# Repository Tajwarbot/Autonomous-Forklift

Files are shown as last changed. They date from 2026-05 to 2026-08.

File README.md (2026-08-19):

# Vision-Guided Autonomous Forklift

A student-built autonomous material-handling robot that follows a guided line, picks up a box, reads a QR route command with a Raspberry Pi, selects the correct branch at a T-junction, delivers the[...]

> **Project status:** working educational prototype for a controlled track. It is not an industrial forklift, safety-rated AMR, or certified material-handling system.

---

## What the robot does

The robot uses two controllers with separate responsibilities:

- **Raspberry Pi 4B:** USB-camera image acquisition, QR detection/decoding, route-command generation.
- **Arduino Mega 2560:** IR line following, motor control, T-junction handling, fork-servo control, station detection, calibration, and mission state.

A QR code contains only one route character:

| QR content | Action at outbound T-junction |
|---|---|
| `l` | Turn left |
| `r` | Turn right |

On the return trip, the Arduino automatically uses the opposite turn so the robot can return to the pickup branch.

---

## System overview

```mermaid
flowchart LR
    CAM[USB Camera] --> PI[Raspberry Pi 4B\nOpenCV + pyzbar]
    PI -- "UART: l / r @ 9600 baud" --> MEGA[Arduino Mega 2560]

    IR[6-channel IR sensor array] --> MEGA
    MEGA --> LEFT[BTS7960\nLeft drive]
    MEGA --> RIGHT[BTS7960\nRight drive]
    LEFT --> LM[2 × left DC motors]
    RIGHT --> RM[2 × right DC motors]
    MEGA --> SERVO[Forklift servo]

    BAT[3S LiPo battery] --> POWER[Power distribution\n+ buck converters]
    POWER --> PI
    POWER --> MEGA
    POWER --> LEFT
    POWER --> RIGHT
    POWER --> SERVO
```

The Raspberry Pi does not directly drive the motors. It sends the decoded route to the Arduino, while the Arduino handles real-time movement and station/junction behavior.

---

## Mission flow

The following flow matches the current QR-based firmware logic.

```mermaid
flowchart TD
    A[Power on] --> B[Arduino loads saved IR calibration from EEPROM]
    B --> C[Start Raspberry Pi QR scanner]
    C --> D[Start Arduino line-following mode]
    D --> E[Follow line to pickup station]
    E --> F[Pickup station detected]
    F --> G[Lift box]
    G --> H[5 s settle / QR scan window]
    H --> I[Fixed pickup-station U-turn]
    I --> J[Follow line toward T-junction]

    J --> K{Valid QR route received?}
    K -- No --> L[Stop at junction and wait]
    L --> K
    K -- l --> M[Turn left]
    K -- r --> N[Turn right]

    M --> O[Follow line to target station]
    N --> O
    O --> P[Drop box]
    P --> Q[Set return state + reverse briefly]
    Q --> R[5 s settle pause]
    R --> S[Fixed drop-station U-turn]
    S --> T[Follow line back to T-junction]
    T --> U[Turn opposite to saved outbound route]
    U --> V[Return to pickup station]
    V --> W[Clear old route and start next cycle]
    W --> G
```

The firmware runs continuously until the robot is stopped or powered off; there is no automatic mission `End` state in the current Arduino loop.

---

## Suggested track layout

```text
LEFT DROP STATION                       RIGHT DROP STATION
        │                                        │
        │                                        │
        └────────────────┬───────────────────────┘
                         │
                         │
                    T-JUNCTION
                         │
                         │
                         │
                         │
                  PICKUP / HOME
```

For the current sensor logic, the track geometry matters:

- Normal guided line: usually one or two sensors active.
- Full T-junction region: all six sensors can become active.
- Pickup/drop station: all six sensors read the station background long enough to trigger the station routine.

The current firmware treats an all-clear sensor condition as a station after approximately 350 ms, so a completely lost line can also resemble a station. Keep the station geometry consistent and [...]

---

## Electrical architecture

circuit diagram

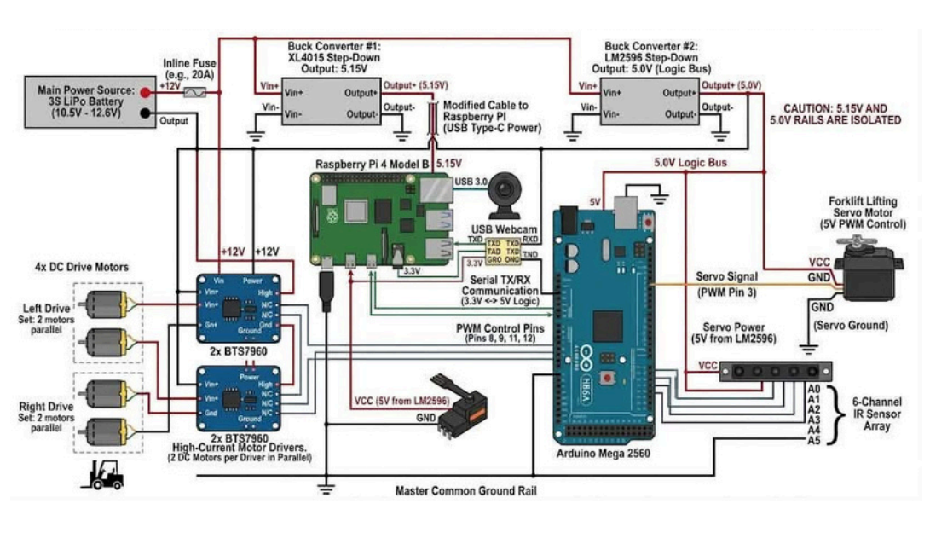
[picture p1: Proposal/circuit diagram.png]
Autonomous Forklift Circuit Diagram


### Detailed circuit diagram

```md
![Autonomous Forklift Circuit Diagram](Proposal/circuit diagram.png)
```

**Important:** the circuit diagram must match the firmware. In the current Arduino code, the fork servo signal is **D5**, while **D3** is the push button. Do not publish a schematic that labels the se[...] 

### Power notes

The current design uses separate regulated positive rails for the Raspberry Pi and 5 V logic/servo supply. Do not tie the **5.15 V** and **5.0 V** positive outputs together. A common ground betwe[...]

The Arduino Mega TX pin is a 5 V logic output. Do not connect Mega TX1 directly to the Raspberry Pi RX pin; use the voltage divider or a suitable logic-level shifter shown in the schematic.

---

## Arduino Mega pin map

| Function | Arduino Mega pin | Connection |
|---|---:|---|
| Left motor forward PWM | D9 | Left BTS7960 RPWM |
| Left motor reverse PWM | D8 | Left BTS7960 LPWM |
| Right motor forward PWM | D12 | Right BTS7960 RPWM |
| Right motor reverse PWM | D11 | Right BTS7960 LPWM |
| Fork servo signal | D5 | Servo signal |
| Start/calibration button | D3 | Button to GND using `INPUT_PULLUP` |
| IR sensor 1-6 | A0-A5 | 6-channel IR sensor array |
| UART RX1 | D19 | Raspberry Pi GPIO14/TXD, header pin 8 |
| UART TX1 | D18 | Through divider/level shifting to Pi GPIO15/RXD, header pin 10 |
| Ground | GND | Common ground |

---

## Hardware required

| Item | Quantity | Purpose |
|---|---:|---|
| Raspberry Pi 4B | 1 | QR vision and high-level route command |
| Arduino Mega 2560 | 1 | Real-time robot control |
| USB webcam | 1 | QR image acquisition |
| 6-channel analog IR sensor array | 1 | Line and junction detection |
| BTS7960 motor driver | 2 | Left/right drivetrain control |
| DC geared motors | 4 | Two motors per side |
| Forklift lifting servo | 1 | Lift/drop mechanism |
| 3S LiPo battery | 1 | Main power source |
| XL4015 step-down converter | 1 | Raspberry Pi supply, adjusted to the required output before connection |
| LM2596 step-down converter | 1 | 5 V logic/servo supply |
| Inline fuse and holder | 1 | Main battery protection |
| Voltage divider or logic-level shifter | 1 | Mega TX → Pi RX protection |
| Push button | 1 | Calibration/run input |
| Fork/chassis/wheels/hardware | as required | Mechanical assembly |

Exact motor model, wheel diameter, sensor mounting height, chassis dimensions, and fork geometry should be documented in `hardware/` before calling the build fully reproducible.

---

## Recommended repository structure

```text
Autonomous-Forklift/
├── README.md
├── LICENSE
├── CONTRIBUTING.md
│
├── firmware/
│   └── arduino-mega/
│       └── AutonomousForklift.ino
│
├── raspberry-pi/
│   ├── qr_router.py
│   └── requirements.txt
│
├── docs/
│   ├── images/
│   │   ├── robot-overview.jpg
│   │   ├── circuit-diagram.png
│   │   ├── system-process-flow.png
│   │   └── track-layout.png
│   ├── CALIBRATION.md
│   └── TROUBLESHOOTING.md
│
├── hardware/
│   ├── BOM.csv
│   ├── circuit/
│   └── CAD/
│
├── qr-codes/
│   ├── left.png
│   └── right.png
│
├── demo/
│   └── QARGO-demo.mp4
│
├── simulation/
│   └── simulation.py
│
└── proposal/
    └── autonomous_material_handling_robot_proposal_fixed.pdf
```

This layout separates the tested firmware, Raspberry Pi software, documentation, hardware files, QR assets, and demonstration media so a new builder can find each part without searching through e[...]

---

# Replication guide

## 1. Build the mechanical platform

Assemble the chassis with two drive motors on the left and two on the right. The two motors on each side are driven together, creating differential-drive steering.

Mount the fork servo so that the mechanical end positions match the firmware:

```cpp
forklift.write(180);  // fork down
forklift.write(0);    // fork up
```

Before powering the servo, verify that these angles do not force the linkage beyond its mechanical limits.

Mount the six IR sensors at the front/bottom of the robot with consistent spacing and height. Record the final sensor height and spacing in `hardware/` so other builders can reproduce the same be[...]

---

## 2. Wire the electronics

Follow the circuit diagram and the pin table above.

Before connecting the Raspberry Pi or Arduino:

1. Set the XL4015 output with a multimeter.
2. Set the LM2596 output with a multimeter.
3. Verify polarity.
4. Verify that the Pi and logic positive rails are not accidentally connected together.
5. Verify common ground.
6. Verify the Mega TX → Pi RX level reduction.
7. Check for shorts before connecting the battery.

Do not tune buck-converter output while sensitive electronics are connected.

---

## 3. Upload the Arduino firmware

Open the tested firmware in the Arduino IDE.

Recommended location:

```text
firmware/arduino-mega/AutonomousForklift.ino
```

Select:

```text
Board: Arduino Mega or Mega 2560
Processor: ATmega2560
```

Upload the sketch.

The firmware uses the standard Arduino `EEPROM` and `Servo` libraries.

For debugging, open the USB Serial Monitor at:

```text
115200 baud
```

The Raspberry Pi communicates separately with `Serial1` at:

```text
9600 baud
```

---

## 4. Prepare the Raspberry Pi

The current vision program requires Python 3, OpenCV, NumPy, `pyzbar`, `pyserial`, and the ZBar runtime.

On Raspberry Pi OS:

```bash
sudo apt update
sudo apt install -y python3-opencv python3-venv libzbar0

python3 -m venv --system-site-packages .venv
source .venv/bin/activate
python -m pip install --upgrade pip
pip install numpy pyzbar pyserial
```

Enable the Raspberry Pi UART:

```bash
sudo raspi-config
```

In the serial-port settings:

```text
Login shell over serial: No
Serial hardware enabled: Yes
```

Then reboot:

```bash
sudo reboot
```

If the user does not have serial-port permission:

```bash
sudo usermod -aG dialout $USER
```

Log out/reboot after changing group membership.

The current Python program uses:

```python
SERIAL_PORT = "/dev/ttyS0"
BAUD_RATE = 9600
```

If your Pi exposes the UART under another device such as `/dev/serial0`, update `SERIAL_PORT` accordingly.

---

## 5. Connect and test the camera

The current script opens camera index `0`:

```python
cap = cv2.VideoCapture(0)
```

Connect the USB webcam and confirm that it appears as the expected video device.

The script displays a live OpenCV window. If you run the Raspberry Pi headless, modify the script to remove or disable the GUI calls (`cv2.imshow()` / keyboard window handling).

---

## 6. Prepare the QR codes

The route QR must contain exactly one useful command:

```text
l
```

or

```text
r
```

The Python script converts input to lowercase and ignores any decoded string other than `l` or `r`.

For a reproducible repository, include ready-to-print QR images in:

```text
qr-codes/left.png
qr-codes/right.png
```

Place the QR on the box where the pickup-station camera can read it reliably during the stationary pickup period.

---

## 7. Calibrate the IR sensors

Calibration values are stored in Arduino EEPROM and loaded at startup.

The current button behavior is:

| Button action | Firmware mode |
|---|---|
| One press | Calibrate IR array |
| Quick double press | Start line following |

During calibration, the robot rotates while sampling each IR channel. Make sure the sensor array sees both the line and the background during this process.

Recalibrate whenever you change:

- Track material or color
- Lighting conditions
- Sensor height
- Sensor angle
- IR module

---

## 8. Run the Raspberry Pi program

From the repository root:

```bash
source .venv/bin/activate
python raspberry-pi/qr_router.py
```

Expected terminal output includes messages similar to:

```text
Starting QR Code Scanner with ZBar...
Data found: l
Sent to Arduino: l
```

The Raspberry Pi sends a single `l` or `r` character through UART. The current script applies a 0.3 s anti-spam interval before resending the same command.

---

## 9. Start the robot

Recommended startup sequence:

1. Place the robot on the track with the fork down.
2. Place a box at the pickup station with a readable `l` or `r` QR code.
3. Power the robot.
4. Start the Raspberry Pi QR program.
5. Confirm camera detection.
6. Confirm Arduino debug output if using the Serial Monitor.
7. Quick double-press the Arduino control button to start line following.
8. Keep a physical power disconnect accessible during testing.

Expected mission:

```text
Pickup/Home
   ↓
Lift box
   ↓
Read QR route
   ↓
T-junction
   ├── l → Left target
   └── r → Right target
   ↓
Drop box
   ↓
Return using opposite junction turn
   ↓
Pickup/Home
   ↓
Repeat
```

---

## Serial protocol

### Raspberry Pi → Arduino

| Data | Meaning |
|---|---|
| `l` | Select left target for current outbound delivery |
| `r` | Select right target for current outbound delivery |

The Arduino also accepts uppercase `L` and `R` and normalizes them internally.

### Arduino → Raspberry Pi

After accepting a valid command, the Arduino sends an acknowledgement similar to:

```text
ACK l
```

or

```text
ACK r
```

The current Raspberry Pi script does not yet use this acknowledgement for closed-loop command confirmation; it is available for future reliability improvements.

---

## Important firmware behavior

The Arduino keeps several mission states:

| State | Purpose |
|---|---|
| `side` | Saved QR route for the current box |
| `route_received` | Confirms that a usable route exists |
| `box_loaded` | Distinguishes pickup from drop station behavior |
| `returning` | Distinguishes outbound and return routing |
| `station_locked` | Prevents the same station from triggering twice while the robot is leaving it |

At an outbound junction, the robot uses the saved QR route. During the return trip, the same route is kept but reversed logically:

```text
Outbound l → Return r
Outbound r → Return l
```

When the robot physically reaches the pickup station again, the old route is cleared so the next box can provide a new QR command.

---

## Main tuning parameters

These values are in the Arduino firmware and may need adjustment for another chassis or track.

| Parameter | Current value | Function |
|---|---:|---|
| `node_delay` | 200 ms | Junction transition delay |
| `u_turn_delay` | 350 ms | Time required before an all-clear region is accepted as a station |
| `u_turn_pause` | 5000 ms | Station settling / QR-reading pause |
| `brake_time` | 50 ms | Active braking duration |
| `turn_brake` | 80 ms | Turn correction braking |
| `station_unlock_time` | 250 ms | Stable normal-line time before the same station can trigger again |
| `spl` | 8 | Left motor speed scale |
| `spr` | 8 | Right motor speed scale |

Do not copy these tuning values blindly to a robot with different motors, wheel diameter, battery voltage, mass, sensor spacing, or track geometry.

---

## Troubleshooting

| Problem | Check |
|---|---|
| Robot stops at the T-junction | No valid `l/r` route may have reached the Arduino. Check QR detection, UART, baud rate, and common ground. |
| Pi detects QR but Arduino shows no command | Check Pi TX → Mega RX1 D19, serial device path, permissions, and 9600 baud. |
| Raspberry Pi RX is damaged/unreliable | Confirm Mega TX1 is not connected directly to Pi RX; use level reduction. |
| Robot turns opposite to expected direction | Check left/right motor wiring, motor polarity, and physical branch orientation. |
| Line following oscillates | Recalibrate IR sensors; check sensor height; reduce speed or retune `spl/spr`. |
| Robot treats a lost line as a station | Improve track geometry/alignment; the current station detector uses the all-clear sensor state. |
| Pickup/drop repeats at the same station | Check station width and line reacquisition. Current firmware includes `station_locked` protection, but the track must still allow a clean exit. |
| Fork moves the wrong way | Verify linkage and servo endpoints before changing the 0°/180° commands. |
| Camera does not open | Check USB camera connection and `VideoCapture(0)` device index. |
| `/dev/ttyS0` permission denied | Add the user to `dialout`, then log out or reboot. |

---

## Safety

This project switches relatively high motor current and uses a LiPo battery. Treat it as a laboratory prototype.

- Use an appropriately selected fuse and wiring gauge.
- Verify converter output voltage before connecting electronics.
- Never connect 5 V logic directly into Raspberry Pi GPIO input pins.
- Keep a fast physical power-disconnect method accessible.
- Raise the drive wheels off the floor during first motor-direction tests.
- Secure the battery and exposed high-current terminals.
- Do not operate near people, stairs, traffic, or valuable equipment during tuning.
- Do not use this prototype for real industrial lifting or personnel transport.

The current tested firmware does **not** implement certified obstacle avoidance, emergency-stop logic, localization, or industrial functional safety.

---

## Acknowledgements

Built as an educational mechatronics and autonomous material-handling project using Raspberry Pi, Arduino, computer vision, embedded control, line sensing, and differential-drive motion.

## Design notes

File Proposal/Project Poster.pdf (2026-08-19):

INTRODUCTION

OBJECTIVES

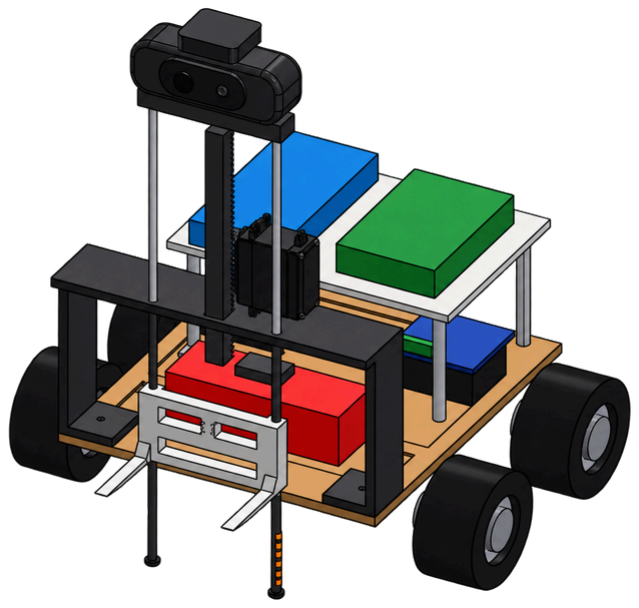
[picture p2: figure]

REFERENCES

METHODOLOGY | RESULTS & DISCUSSION

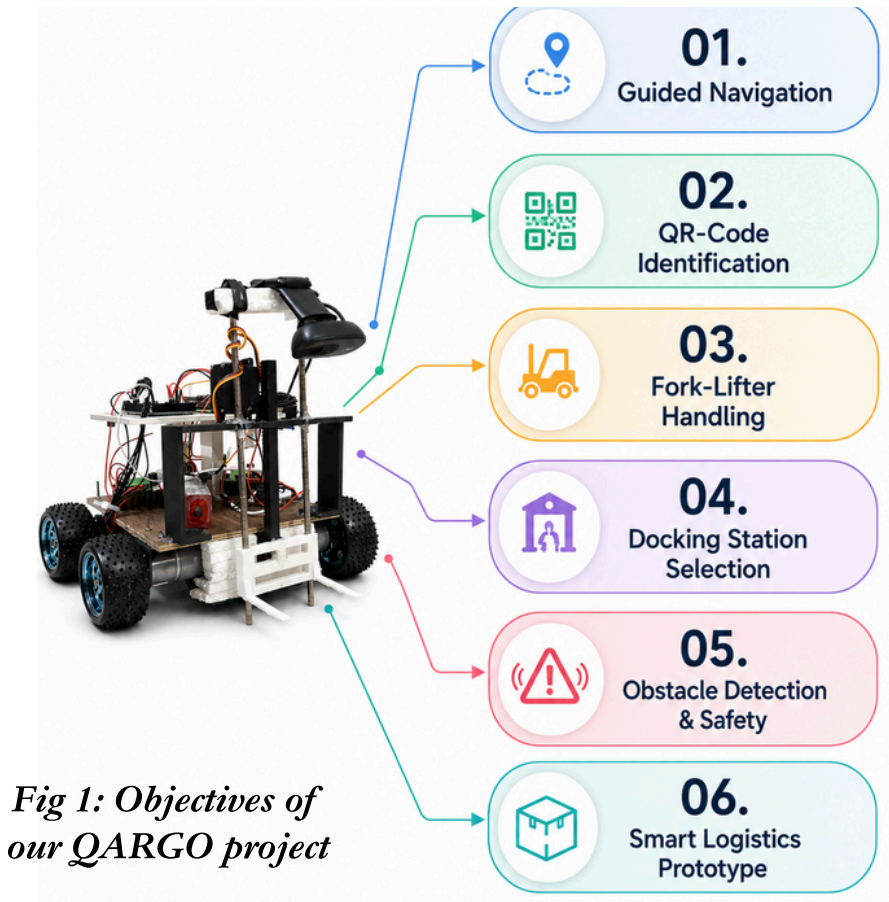
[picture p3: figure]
Fig 1: Objectives of our QARGO project

SCHEMATIC DIAGRAMS

# QARGO - QR Assisted Robotic Goods Operator

D.Hridraz (230012132-Group Leader), M.S.Tamim (230012101), M.Mohian (230012109),
A. Sultana (230012125), M.A. Muiz (230012126), M.A. Rahman (230012141), I.Hossain (230012148), M.S.I. Sujal (230012149), A.T. Tajwar (230012150), N. Feeda (230012151)

ISLAMIC UNIVERSITY OF TECHNOLOGY (IUT)

Autonomous material-handling robots improve efficiency, accuracy, and safety in warehouses and production systems. In many industries, manual handling and transportation of heavy goods are physically demanding, time-consuming, and prone to human error, creating the need for safer and more automated material-handling solutions. Vision-guided forklift research has demonstrated automatic pallet engagement using camera-based guidance [1], while QR-based goods-segregation robots have combined web-camera scanning, line following, IR sensing, and forklift mechanisms to identify goods and transport them to designated locations [2]. Inspired by these approaches, our project QARGO (QR Assisted Robotic Goods Operator) uses a 6-channel IR sensor array for guided navigation, a Raspberry Pi 4B and camera for QR-code identification and destination selection, and an Arduino Mega 2560 for motor, sensor, and fork-lifter control. The system autonomously picks, identifies, transports, and delivers blocks to their assigned docking stations.

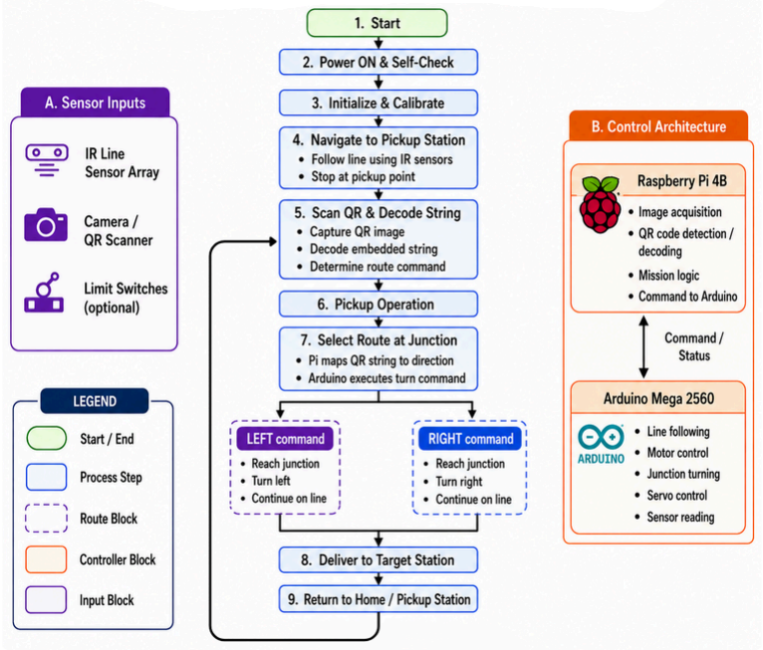
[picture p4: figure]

Key Working Principle:

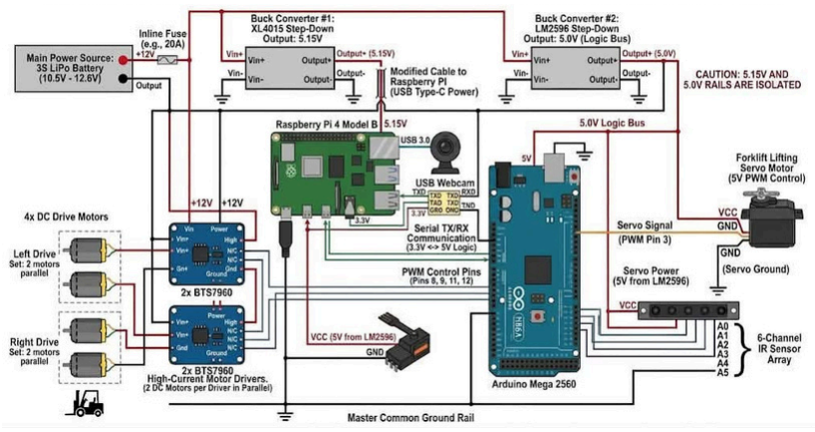
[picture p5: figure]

DEPARTMENT OF MECHANICAL AND PRODUCTION ENGINEERING

The QARGO system was developed through a stepwise mechatronic process integrating guided navigation, QR-based decision making, and automated material handling.
System & Chassis Design
Component Integration
IR Line Following
QR Code Scanning
Dock Selection
Fork-Lifter Control
Testing & Validation

The developed QARGO prototype successfully integrates the major subsystems required for autonomous material handling: guided line navigation, QR-code identification, destination selection, obstacle sensing, and fork-lifter actuation. The 6-channel IR sensor array provides line-following feedback, while the Raspberry Pi processes QR information and the Arduino Mega controls the motors and actuators.
During integration, system performance was found to depend strongly on line-sensor calibration, QR visibility, camera alignment, fork positioning, and stable power supply. QR codes must remain clearly visible during scanning, while accurate pickup requires proper alignment between the fork and wooden block. Reliable serial communication between the Raspberry Pi and Arduino is also essential for correct docking decisions.

Conclusions:
Integrated autonomous material handling achieved.
QR-based dock selection implemented. IR-guided navigation established.
Fork-lifter mechanism integrated.
Calibration and mechanical alignment affect reliability.
Further repeated trials are required for quantitative performance evaluation. Coordination and synchronization among
multiple | QARGO | robots | operating
simultaneously is yet to be implemented.
[1] M. Seelinger and J.

-D. Yoder,

“Automatic
visual guidance of a forklift engaging a pallet,

”
Robotics and Autonomous Systems, Vol. 54, No. 12, pp. 1026–1038, 2006.
[2] K. Bhavana, B. Lalitha, T. Srinivasa Rao, and
M. V. Ramesh,

“Goods Segregation Robot for Industry,

” International Journal of Emerging Trends in Engineering Research, Vol. 8, No. 9, pp. 5828–5831, 2020.

MIC LAB (ME- 4408) | Academic Year: 2024-25

Group
IPE
01
Chassis: | Modular | frame | supporting
electronics, drive system, camera, sensors, and fork-lifter.
6-Channel IR Sensor Array: Detects the black line and provides feedback for guided navigation.
Camera / Webcam: Scans QR codes for
block | identification | and | destination
selection.
Raspberry Pi 4B: Handles QR decoding, destination mapping, mission logic, and Arduino communication.
Arduino Mega 2560: Controls line following, motors, servos, sensors, and safety functions.
Drive Motors: Four 12 V, 130 RPM gear
motors | provide | stable | four-wheel
movement.
Motor Drivers: BTS motor driver controls high-current motor operation.
Fork-Lifter Mechanism: MG996R high-torque servo performs lifting and lowering; SG90 assists block release.
Power Supply: 3S 11.1 V LiPo battery supplies power through 2 buck converters: 1× LM2596 and 1× XL4015 for regulated voltage distribution.
Fig 2: CAD Model of QR Assisted Robotic Goods Operator | Fig 4: Circuit Diagram

Fig 3: System Flowchart

Supervised by: F.T Mohsin, S.A Bari, F.Tabassum

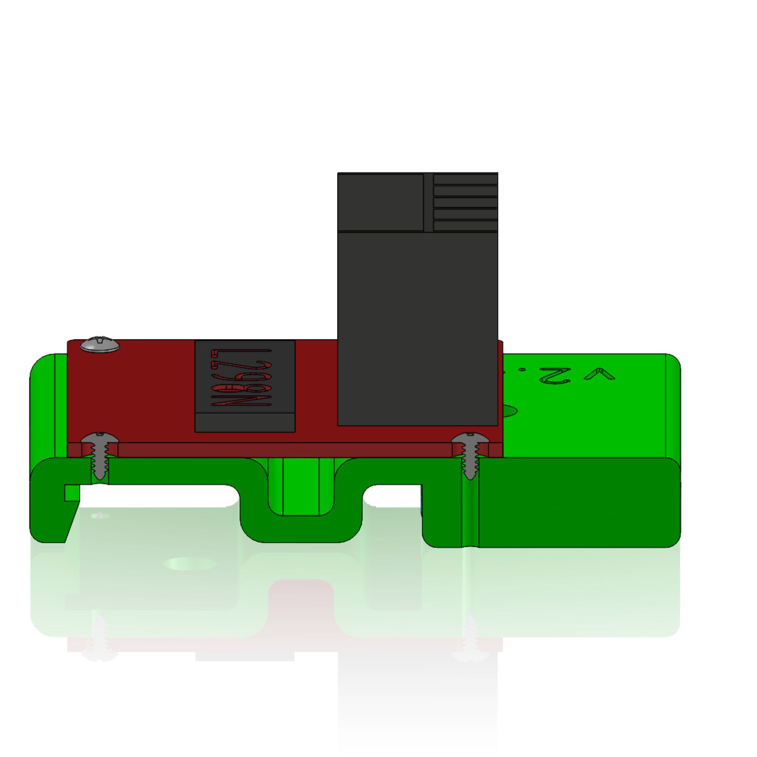
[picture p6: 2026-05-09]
CAD/GrabCAD/motordriver-1.snapshot.8/IMG/img_driver1.jpg

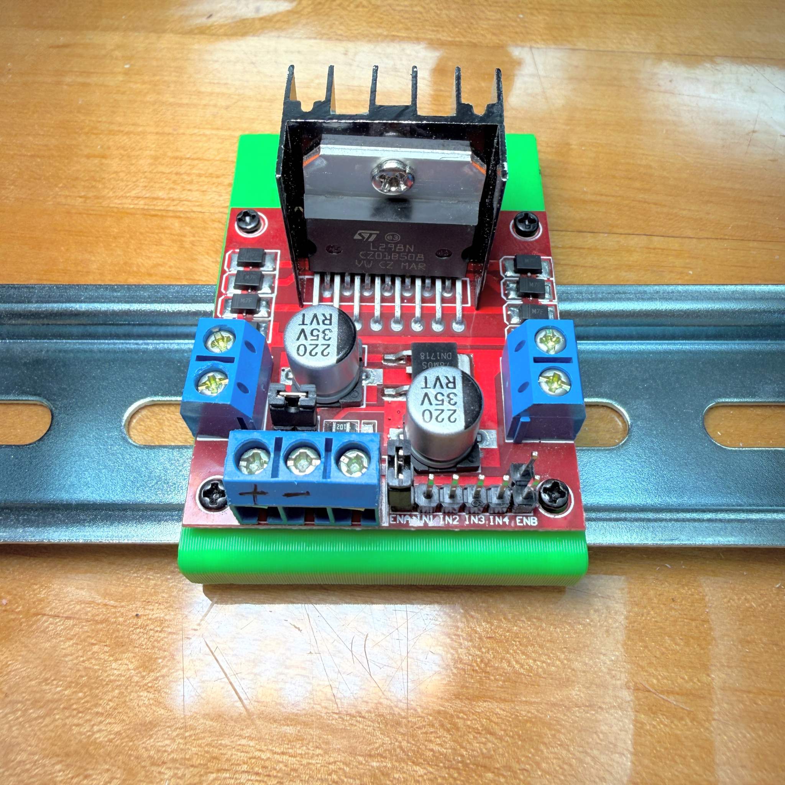
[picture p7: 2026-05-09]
CAD/GrabCAD/motordriver-1.snapshot.8/IMG/photo_driver2.jpg

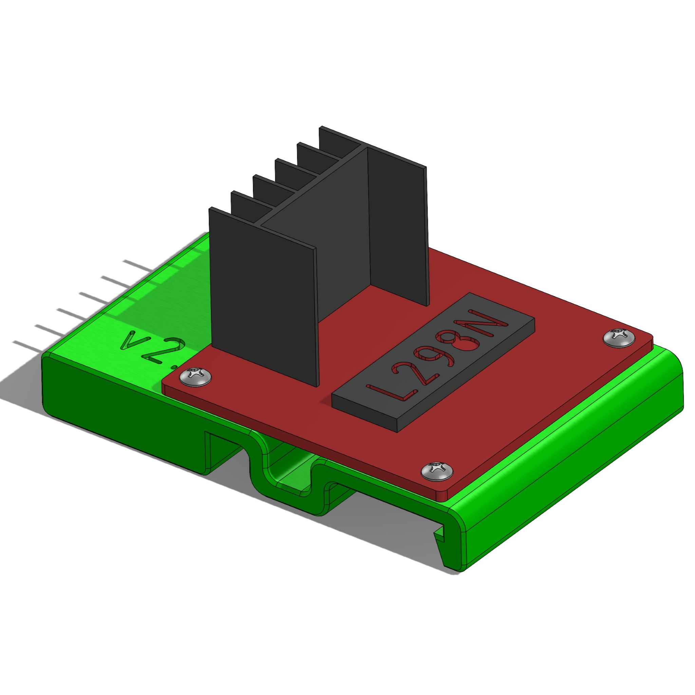
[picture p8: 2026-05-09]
CAD/GrabCAD/motordriver-1.snapshot.8/IMG/img_driver3.jpg

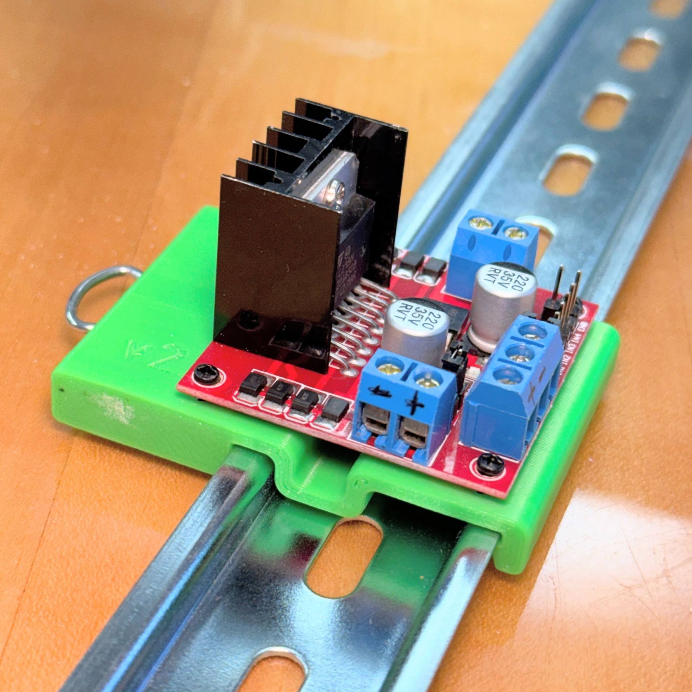
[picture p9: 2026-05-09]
CAD/GrabCAD/motordriver-1.snapshot.8/IMG/photo_driver1.jpg

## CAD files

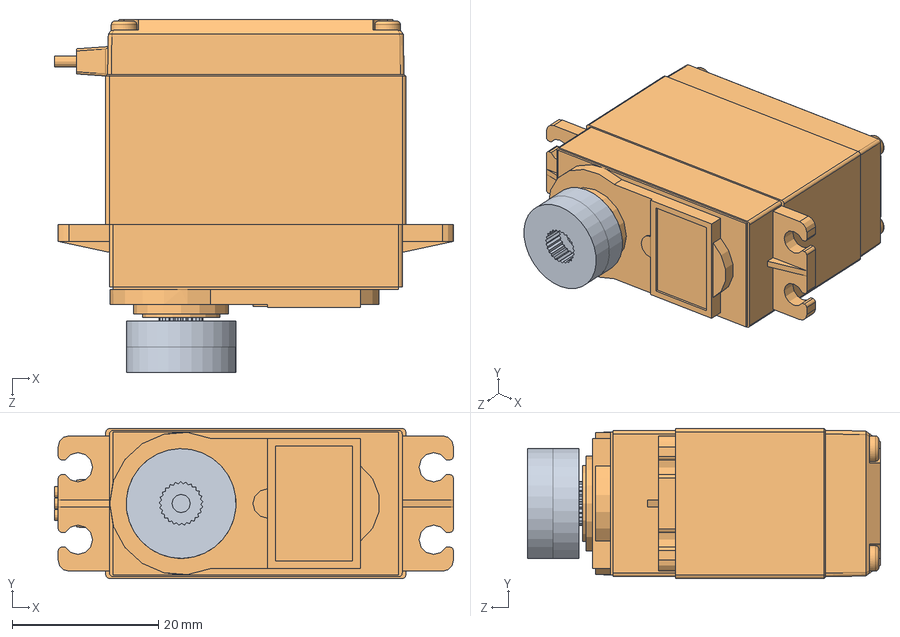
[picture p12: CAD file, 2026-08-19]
CAD/MG996R SBORKA.SLDASM
54.5 x 20.5 x 48.2 mm
Servo MG996R
Servo MG996R Shaft

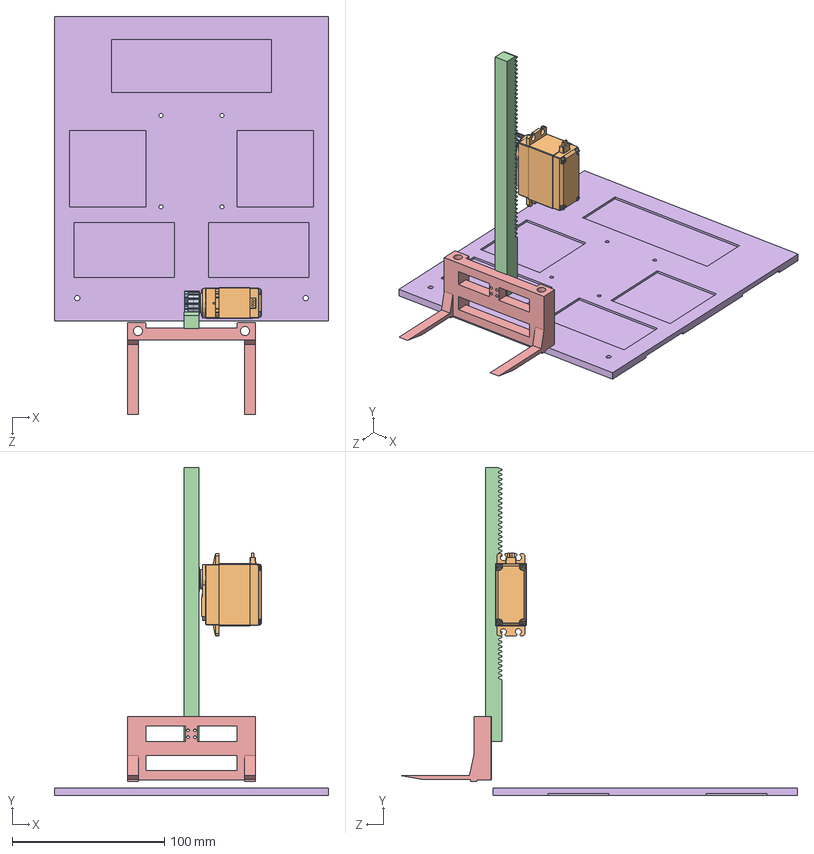
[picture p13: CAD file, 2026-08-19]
CAD/front stand.SLDASM
180.0 x 215.7 x 261.4 mm
Chassis Bottom plate(1)
Fork
rackk ishrak
spur gear ishrak
Servo MG996R
Servo MG996R Shaft

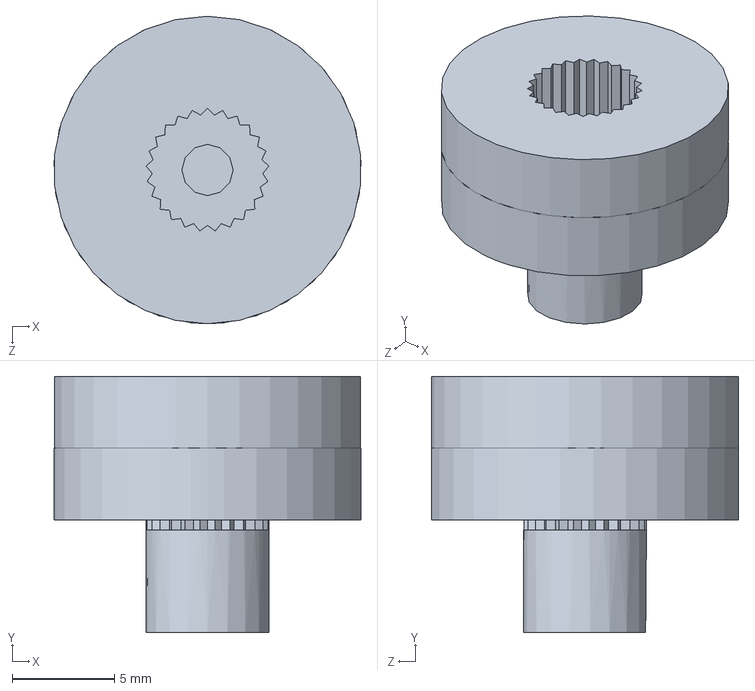
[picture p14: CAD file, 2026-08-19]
CAD/Servo MG996R Shaft.SLDPRT
15.0 x 12.5 x 15.0 mm

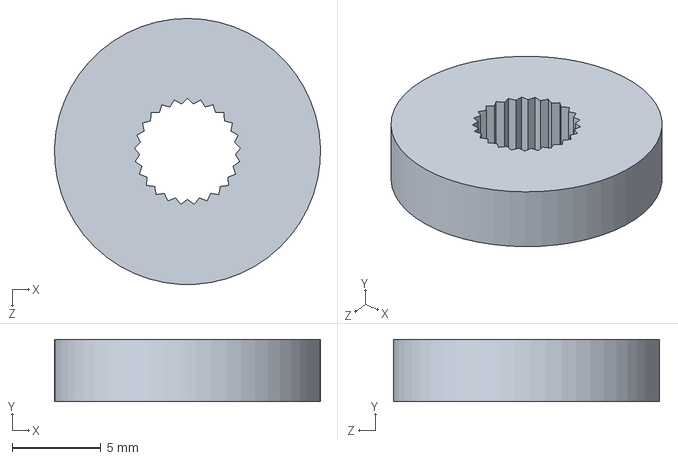
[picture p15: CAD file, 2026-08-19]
CAD/Body1.SLDPRT
15.0 x 3.50 x 15.0 mm

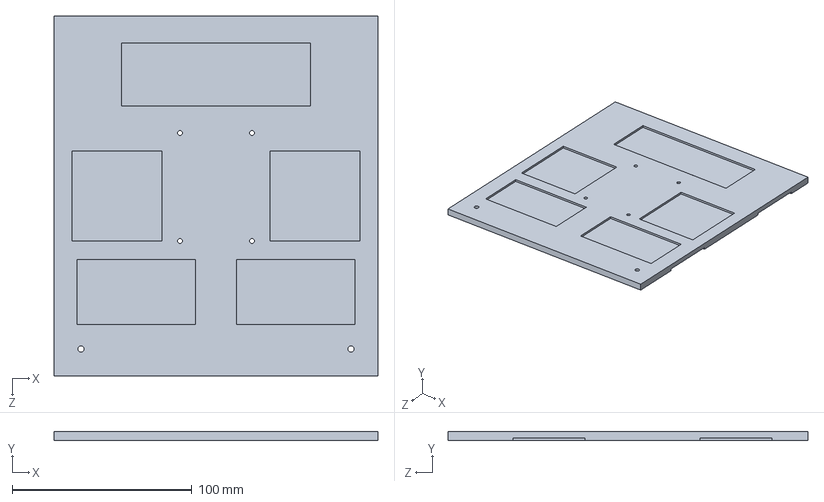
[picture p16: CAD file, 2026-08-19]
CAD/Chassis Bottom plate(1).SLDPRT
180.0 x 5.00 x 200.0 mm

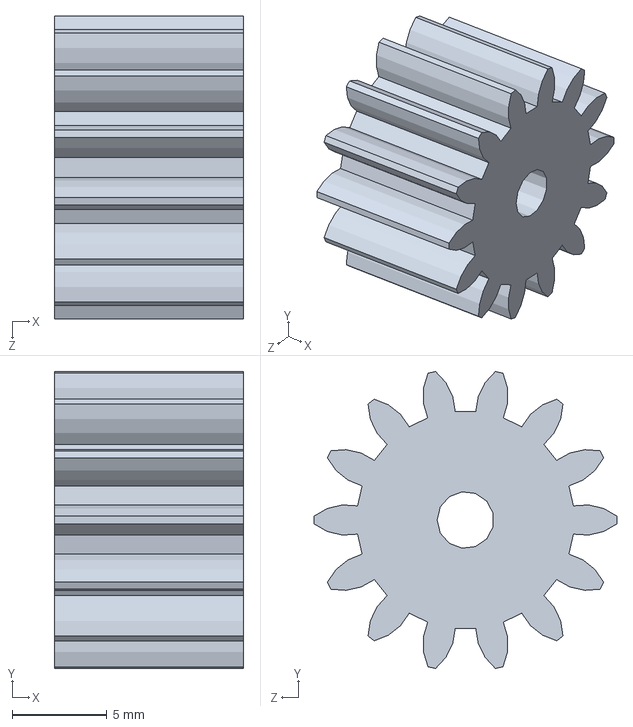
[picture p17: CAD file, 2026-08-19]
CAD/spur gear ishrak.SLDPRT
10.0 x 15.7 x 16.0 mm

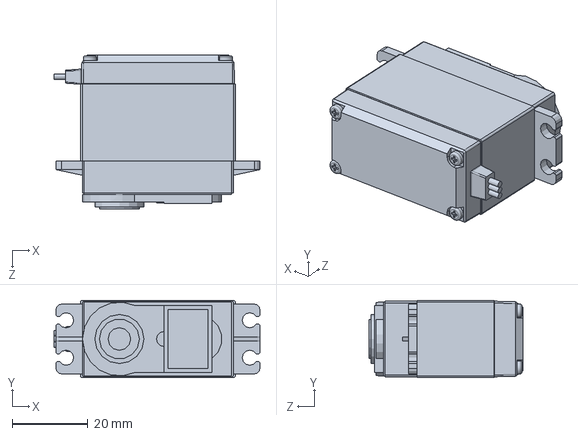
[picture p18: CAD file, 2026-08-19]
CAD/Servo MG996R.SLDPRT
54.5 x 20.5 x 40.7 mm

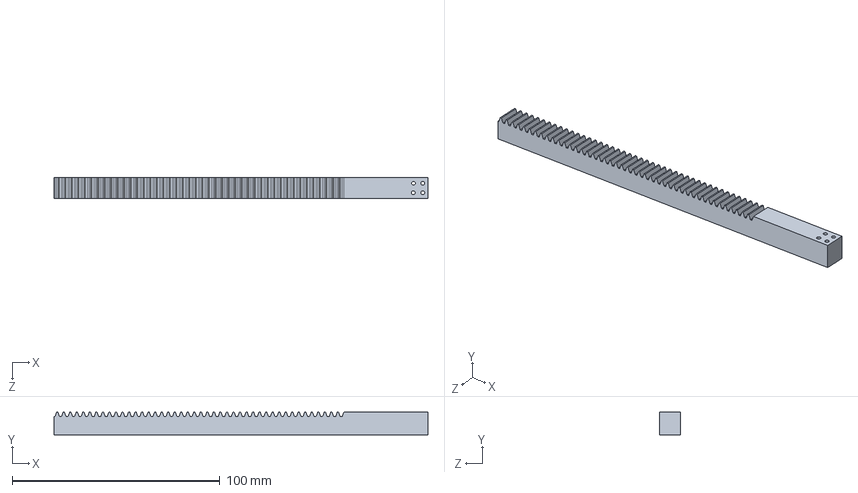
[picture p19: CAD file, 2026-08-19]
CAD/rackk ishrak.SLDPRT
180.0 x 11.0 x 10.0 mm

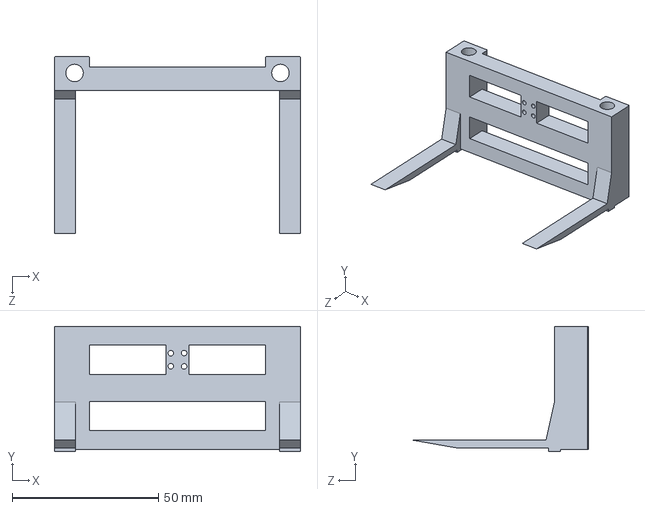
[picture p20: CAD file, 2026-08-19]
CAD/Fork.SLDPRT
84.0 x 42.8 x 60.4 mm

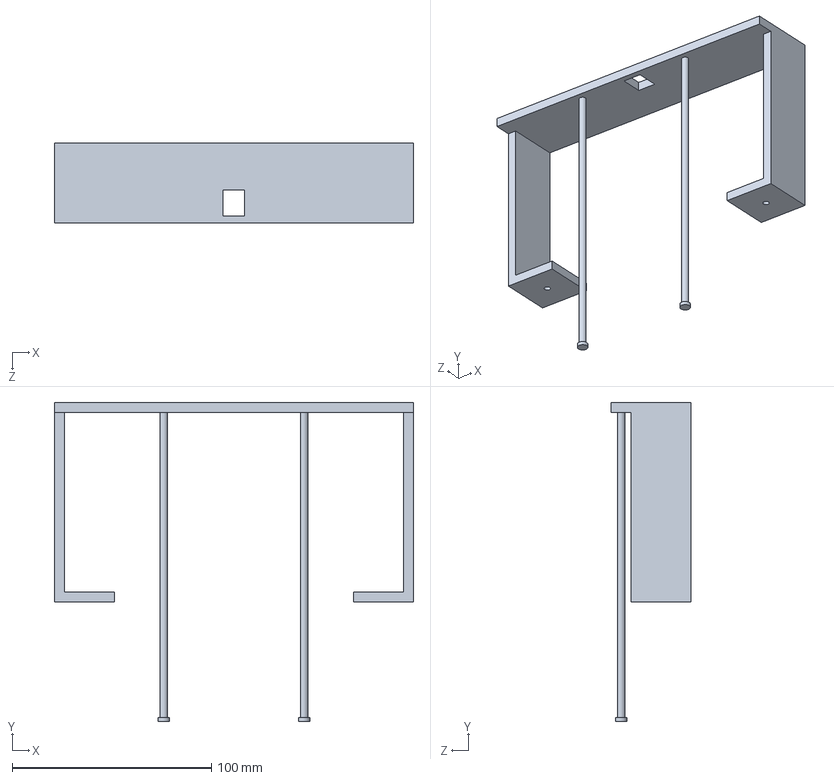
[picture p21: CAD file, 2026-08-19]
CAD/top frame.SLDPRT
180.0 x 160.0 x 40.0 mm

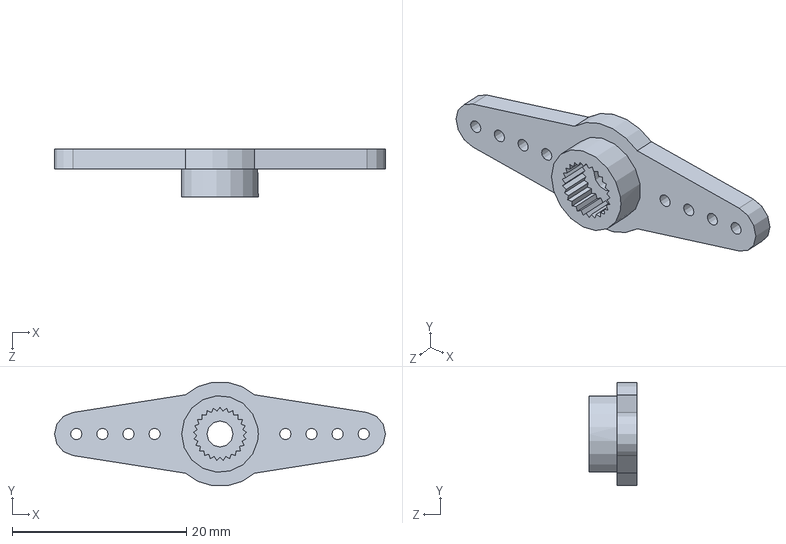
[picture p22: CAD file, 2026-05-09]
CAD/Servo MG996R arm01.SLDPRT
38.0 x 11.9 x 5.50 mm

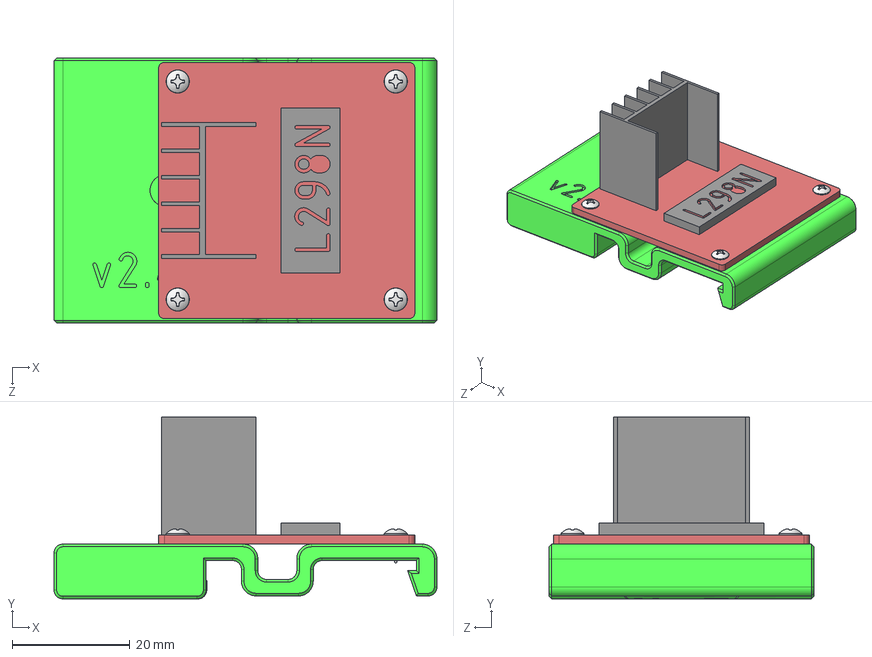
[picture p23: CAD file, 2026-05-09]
CAD/GrabCAD/motordriver-1.snapshot.8/STEP/motorDriverAssy.STEP
65.0 x 30.9 x 45.0 mm
myBracket
H-BridgeL298N
screw_no6_screw_m2.5 x 4

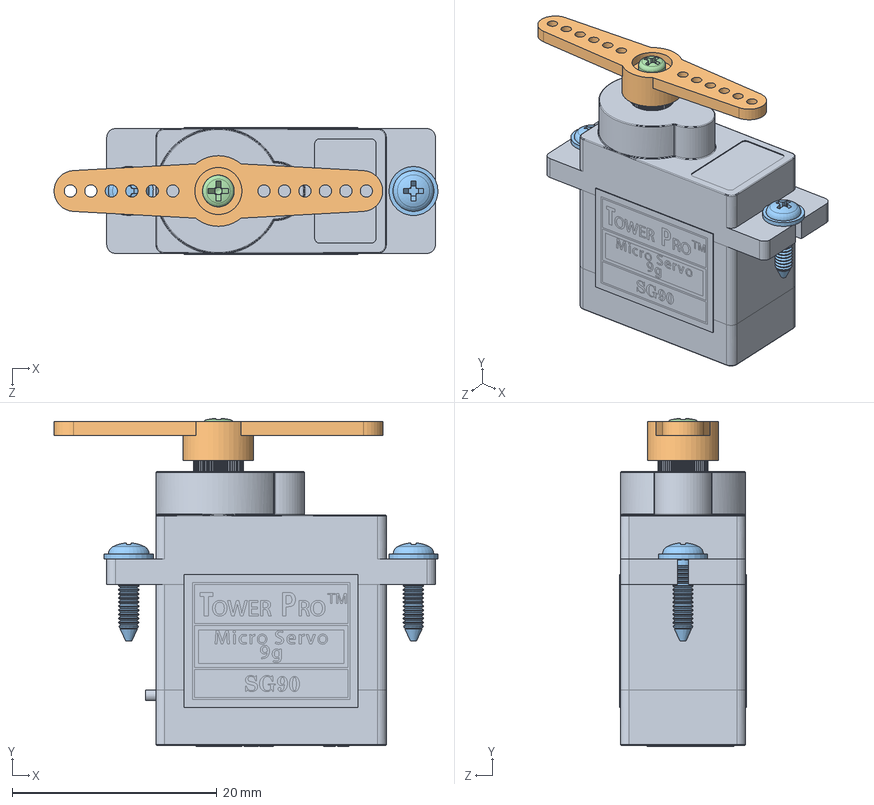
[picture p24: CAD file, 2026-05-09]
CAD/GrabCAD/sg90-micro-servo-9g-tower-pro-1.snapshot.3/SG90 - Micro Servo 9g - Tower Pro.SLDASM
37.5 x 32.0 x 12.4 mm
SG90 - Micro Servo 9g - Tower Pro.1
SG90 - Micro Servo 9g - Tower Pro.3
SG90 - Micro Servo 9g - Tower Pro.5 x 2
SG90 - Micro Servo 9g - Tower Pro.6

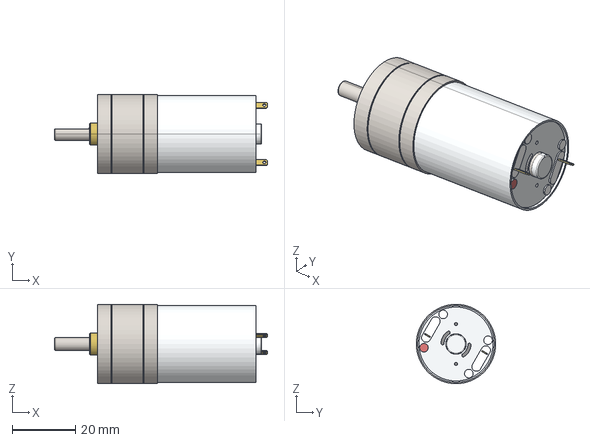
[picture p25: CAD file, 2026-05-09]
CAD/GrabCAD/25ga370-12v-500rpm-20-4-1-gear-motor-1.snapshot.5/Motor_25GA370-20.4x.STEP
67.1 x 25.0 x 25.0 mm
Motor_25GA370-20.4x
M2.5 x 16 x 2

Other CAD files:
CAD/GrabCAD/5-channel-ir-sensor-array-1.snapshot.5/IR sensor array.STEP
CAD/GrabCAD/arduino-mega-2560--1.snapshot.8/ArduinoMega2560/ArduinoMega.SLDPRT
CAD/GrabCAD/arduino-mega-2560--1.snapshot.8/ArduinoMega_STEP_AP203.STEP
CAD/GrabCAD/5-channel-ir-sensor-array-1.snapshot.5/IR sensor array.SLDPRT
CAD/GrabCAD/5-channel-ir-sensor-array-1.snapshot.5/IR sensor array.STL
CAD/GrabCAD/arduino-mega-2560--1.snapshot.8/ArduinoMega.SLDPRT
CAD/GrabCAD/mg996r-servo-motor-1.snapshot.7/MG996R SERVO/MG996R SBORKA.SLDASM
CAD/GrabCAD/mg996r-servo-motor-1.snapshot.7/MG996R SERVO/Servo MG996R Shaft.SLDPRT
CAD/GrabCAD/mg996r-servo-motor-1.snapshot.7/MG996R SERVO/Servo MG996R.SLDPRT
CAD/GrabCAD/motordriver-1.snapshot.8/SOLIDWORKS/H-BridgeL298N.SLDPRT
CAD/GrabCAD/motordriver-1.snapshot.8/SOLIDWORKS/motorDriverAssy.SLDASM
CAD/GrabCAD/motordriver-1.snapshot.8/SOLIDWORKS/myBracket.SLDPRT
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

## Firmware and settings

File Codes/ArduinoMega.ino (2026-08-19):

#include <EEPROM.h>
#include <Servo.h>

// ================== SERIAL PORTS ==================
// Serial  = USB to PC, debug output only (Serial Monitor @ 115200)
// Serial1 = Raspberry Pi link  @ 9600
//           Mega RX1 = pin 19  <-- Pi GPIO14 / TXD (header pin 8)
//           Mega TX1 = pin 18  --> divider --> Pi GPIO15 / RXD (header pin 10)
//           GND to GND is mandatory
#define DEBUG_SERIAL 1  // 1 = print every byte from the Pi, 0 = silent

// ================== MOTOR DRIVER PINS (2x BTS7960) ==================
#define left_RPWM 9    // left forward
#define left_LPWM 8    // left backward
#define right_RPWM 12  // right forward
#define right_LPWM 11  // right backward

// ================== BUTTON ==================
#define sw 3  // one diagonal leg -> D3, other -> GND (INPUT_PULLUP)

// ================== TIMING / TUNING ==================
#define node_delay 200
#define stop_timer 100
#define u_turn_delay 350
#define u_turn_pause 5000  // ms to sit still on white before rotating
#define brake_time 50
#define turn_brake 80

float spl = 8;
float spr = 8;

// ================== STATE VARIABLES ==================
char side = 's';
bool route_received = false;
char flag = 's';

bool box_loaded = false;
bool returning = false;

#define servo_pin 5
Servo forklift;
int pos;
char cross = 's';
uint32_t m1, m2;

// ================== SENSOR VARIABLES ==================
int s[6];
int mid[6], maximum[6], minimum[6];
int base[6] = { 1, 2, 4, 8, 16, 32 };
int sensor;
int sum = 0;

// ================== SETUP ==================
void setup() {
  Serial.begin(115200);  // USB debug
  Serial1.begin(9600);   // Raspberry Pi

  pinMode(left_RPWM, OUTPUT);
  pinMode(left_LPWM, OUTPUT);
  pinMode(right_RPWM, OUTPUT);
  pinMode(right_LPWM, OUTPUT);
  pinMode(sw, INPUT_PULLUP);

  forklift.attach(servo_pin);

  // Start with fork fully DOWN
  forklift.write(180);
  delay(1000);

  for (int i = 0; i < 6; i++) {
    mid[i] = EEPROM.read(i) * 4;
    maximum[i] = EEPROM.read(i + 6) * 4;
    minimum[i] = EEPROM.read(i + 12) * 4;
    Serial.println(String(maximum[i]) + " " + String(mid[i]) + " " + String(minimum[i]));
  }

  motor(0, 0);

  Serial.println(F("ARDUINO READY - waiting for 'l' or 'r' on Serial1"));
  Serial1.println(F("ARDUINO READY"));  // so the Pi can confirm the link
}

// ================== MAIN LOOP ==================
// Press count:  1 = calibrate,  2 = run
void loop() {
  serial_read_pi();  // drain + echo bytes even before the run starts
  int r = button_read();
  if (r == 1) cal();
  else if (r == 2) line_follow();
}

// ================== BUTTON (press counter) ==================
int button_read() {
  int cl = 0;
p:
  int t = 0;
  if (digitalRead(sw) == 0) {
    while (digitalRead(sw) == 0) {
      serial_read_pi();
      delay(1);
      t++;
    }
    if (t > 15) {
      t = 0;
      cl++;
      while (digitalRead(sw) == HIGH) {
        serial_read_pi();
        delay(1);
        t++;
        if (t > 1000) return cl;
      }
      goto p;
    }
  }
  return cl;
}

// ================== RASPBERRY PI SERIAL COMMAND ==================
void serial_read_pi() {
  while (Serial1.available() > 0) {
    char command = Serial1.read();

#if DEBUG_SERIAL
    Serial.print(F("RX '"));
    Serial.print(command);       // printable character
    Serial.print(F("' dec="));
    Serial.print((int)command);  // 108='l' 114='r' 76='L' 82='R' 13=CR 10=LF
    Serial.print(F(" left="));
    Serial.println(Serial1.available());
#endif

    if (command == 'L') command = 'l';
    if (command == 'R') command = 'r';

    if ((command == 'l' || command == 'r') && returning == false) {
      side = command;
      route_received = true;

#if DEBUG_SERIAL
      Serial.print(F("  -> ACCEPT  side="));
      Serial.print(side);
      Serial.print(F("  route_received=1  returning="));
      Serial.println(returning);
#endif
      Serial1.print(F("ACK "));  // tell the Pi the command landed
      Serial1.println(side);
    }
#if DEBUG_SERIAL
    else {
      Serial.print(F("  -> IGNORE  (returning="));
      Serial.print(returning);
      Serial.println(F(")"));
    }
#endif
  }
}

void serial_delay(unsigned long t) {
  unsigned long start = millis();
  while (millis() - start < t) {
    serial_read_pi();
    delay(1);
  }
}

// ================== SENSOR READ (fusion) ==================
void reading() {
  serial_read_pi();

  sensor = 0;
  sum = 0;
  for (int i = 0; i < 6; i++) {
    s[i] = analogRead(i);
    (s[i] < mid[i]) ? s[i] = 0 : s[i] = 1;
    sensor += s[i] * base[i];
    sum += s[i];
  }
}

// ================== MOTOR (BTS7960) ==================
void motor(int a, int b) {
  // ---- left channel ----
  if (a >= 0) {
    if (a > 255) a = 255;
    analogWrite(left_RPWM, a);
    analogWrite(left_LPWM, 0);
  } else {
    a = -a;
    if (a > 255) a = 255;
    analogWrite(left_RPWM, 0);
    analogWrite(left_LPWM, a);
  }
  // ---- right channel ----
  if (b >= 0) {
    if (b > 255) b = 255;
    analogWrite(right_RPWM, b);
    analogWrite(right_LPWM, 0);
  } else {
    b = -b;
    if (b > 255) b = 255;
    analogWrite(right_RPWM, 0);
    analogWrite(right_LPWM, b);
  }
}

// ================== BRAKE ==================
void brake() {
  motor(-9 * spl, -9 * spr);
  serial_delay(brake_time);
  motor(0, 0);
  delay(60);
}

// ================== FORKLIFT SERVO CONTROL ==================
void lift_box() {
#if DEBUG_SERIAL
  Serial.println(F("ACTION: lift box"));
#endif
  forklift.write(0);
  delay(1000);
}

void drop_box() {
#if DEBUG_SERIAL
  Serial.println(F("ACTION: drop box"));
#endif
  forklift.write(180);
  delay(1000);
}

void reverse_before_return() {
  motor(-10 * spl, -10 * spr);
  delay(300);
  motor(0, 0);
  delay(200);
}

char get_junction_turn_direction() {
  if (route_received == false) return 's';
  if (returning == false) return side;
  if (side == 'l') return 'r';
  if (side == 'r') return 'l';
  return 's';
}

// ================== FIXED STATION U-TURN ==================
// QR l/r is ONLY for the route junction.
// Preserve the tested station behavior:
//   outbound pickup station -> LEFT U-turn
//   return/drop station      -> RIGHT U-turn
char get_station_turn_direction() {
  return returning ? 'r' : 'l';
}

char wait_for_junction_turn_direction() {
  char dir = get_junction_turn_direction();

#if DEBUG_SERIAL
  bool warned = false;
#endif

  while (dir != 'l' && dir != 'r') {
#if DEBUG_SERIAL
    if (!warned) {
      Serial.println(F("JUNCTION WAIT: no QR route received yet - motors stopped"));
      warned = true;
    }
#endif
    motor(0, 0);
    serial_read_pi();
    delay(1);
    dir = get_junction_turn_direction();
  }

#if DEBUG_SERIAL
  Serial.print(F("JUNCTION TURN dir="));
  Serial.print(dir);
  Serial.print(F("  (side="));
  Serial.print(side);
  Serial.print(F(" returning="));
  Serial.print(returning);
  Serial.println(F(")"));
#endif

  return dir;
}

// ================== LINE FOLLOW ==================
void line_follow() {
  while (1) {
a:
    reading();
    if (sum == 0) {
      if (flag != 's') {
        brake();
        (flag == 'l') ? motor(-6 * spl, 6 * spr) : motor(6 * spl, -6 * spr);
        while (s[2] == 0 && s[3] == 0) reading();
        (flag == 'r') ? motor(-6 * spl, 6 * spr) : motor(6 * spl, -6 * spr);
        serial_delay(turn_brake);
        flag = 's';
        cross = 's';
        pos = 0;
      } else if (pos > -3 && pos < 3) {
        m2 = millis();
        while (sum == 0) {
          reading();
          if (millis() - m2 > u_turn_delay) {
            brake();
            motor(0, 0);

            // ================= WHITE STATION ACTION =================
            if (box_loaded == false) {
              // PICKUP STATION.
              // If we have just returned from a drop station, the old QR route
              // must be forgotten HERE (not at the return junction), because
              // it was still needed to navigate back to the pickup station.
              if (returning == true) {
                returning = false;
                route_received = false;
                side = 's';
                cross = 's';
                flag = 's';

#if DEBUG_SERIAL
                Serial.println(F("NEW CYCLE: old QR route cleared; waiting for new l/r"));
#endif
              }

              lift_box();
              box_loaded = true;
            } else {
              // DROP STATION. Keep side/route_received unchanged because the
              // same route is required in reverse at the junction on the way home.
              drop_box();
              box_loaded = false;
              returning = true;
              reverse_before_return();
            }
            // ========================================================

            // Intentional pause: let the lifted/dropped box settle.
            serial_delay(u_turn_pause);

            // Station turn is fixed and does NOT depend on QR.
            char station_turn = get_station_turn_direction();

#if DEBUG_SERIAL
            Serial.print(F("STATION U-TURN dir="));
            Serial.print(station_turn);
            Serial.print(F("  QR="));
            Serial.print(side);
            Serial.print(F("  returning="));
            Serial.println(returning);
#endif

            (station_turn == 'l') ? motor(-6 * spl, 6 * spr) : motor(6 * spl, -6 * spr);
            while (s[2] == 0 && s[3] == 0) reading();
            (station_turn == 'r') ? motor(-6 * spl, 6 * spr) : motor(6 * spl, -6 * spr);
            serial_delay(turn_brake);
            pos = 0;
            break;
          }
        }
      }
    }

    else if (sum == 1 || sum == 2) {  // straight line
      if (cross != 's') {
        brake();
        (cross == 'l') ? motor(-6 * spl, 6 * spr) : motor(6 * spl, -6 * spr);
        while (s[4] + s[3] + s[2] + s[1] > 0) reading();
        while (s[2] == 0 && s[3] == 0) reading();
        (cross == 'l') ? motor(-6 * spl, 6 * spr) : motor(6 * spl, -6 * spr);
        serial_delay(turn_brake);
        cross = 's';
        flag = 's';
        pos = 0;
      }
      if (sensor == 0b001100) {
        if (pos != 0) {
          (pos > 0) ? motor(-10 * spl, 10 * spr) : motor(10 * spl, -10 * spr);
          (pos > 0) ? delay(pos * 5) : delay(-pos * 5);
          pos = 0;
        }
        motor(10 * spl, 10 * spr);
      }
      // right side portion
      else if (sensor == 0b000100)
        motor(10 * spl, 9 * spr);
      else if (sensor == 0b000110) {
        if (pos < 1) pos = 1;
        motor(10 * spl, 6 * spr);
      } else if (sensor == 0b000010) {
        if (pos < 2) pos = 2;
        motor(10 * spl, 3 * spr);
      } else if (sensor == 0b000011) {
        if (pos < 3) pos = 3;
        motor(10 * spl, 0 * spr);
      } else if (sensor == 0b000001) {
        if (pos < 4) pos = 4;
        motor(10 * spl, -3 * spr);
      }
      // left side portion
      else if (sensor == 0b001000)
        motor(9 * spl, 10 * spr);
      else if (sensor == 0b011000) {
        if (pos > -1) pos = -1;
        motor(6 * spl, 10 * spr);
      } else if (sensor == 0b010000) {
        if (pos > -2) pos = -2;
        motor(3 * spl, 10 * spr);
      } else if (sensor == 0b110000) {
        if (pos > -3) pos = -3;
        motor(0 * spl, 10 * spr);
      } else if (sensor == 0b100000) {
        if (pos > -4) pos = -4;
        motor(-3 * spl, 10 * spr);
      }
    }

    else if (sum == 3 || sum == 4 || sum == 5) {
      if (s[5] == 1 && s[0] == 0 && s[2] + s[3] > 0) {
        flag = 'l';
        while (s[5] == 1 && s[0] == 0) reading();
        if (s[0] == 0) {
          serial_delay(node_delay);
          reading();
          if (sum != 0)
            cross = wait_for_junction_turn_direction();
        }
      }

      else if (s[0] == 1 && s[5] == 0 && s[2] + s[3] > 0) {
        flag = 'r';
        while (s[5] == 0 && s[0] == 1) reading();
        if (s[5] == 0) {
          serial_delay(node_delay);
          reading();
          if (sum != 0)
            cross = wait_for_junction_turn_direction();
        }
      }
      m1 = millis();
    }

    else if (sum == 6) {
      // Full-black junction. The old code stopped after stop_timer and then
      // waited for sum to change while the motors were OFF. On a wide black
      // junction that can never happen, so the robot can freeze permanently.
      char junction_dir = wait_for_junction_turn_direction();
      flag = junction_dir;

#if DEBUG_SERIAL
      Serial.print(F("FULL JUNCTION: moving through, dir="));
      Serial.println(junction_dir);
#endif

      // Keep moving forward until the outer sensors start leaving the solid
      // junction. The timeout prevents this loop from trapping the robot if
      // the junction is unusually wide or a sensor stays active.
      m2 = millis();
      while ((s[5] == 1 || s[0] == 1) && (millis() - m2 < 650)) {
        motor(7 * spl, 7 * spr);
        reading();
      }

      serial_delay(node_delay);
      reading();

      // Reuse the direction already chosen above. Do not ask for the route a
      // second time at the same junction.
      if (sum != 0) cross = junction_dir;
      m1 = millis();
    }
    if (millis() - m1 > 500) flag = 's';
  }
}

// ================== CALIBRATION ==================
void cal() {
  for (int i = 0; i < 6; i++) {
    maximum[i] = 0;
    minimum[i] = 1023;
  }
  motor(120, -120);
  for (int j = 0; j < 5000; j++) {
    for (int i = 0; i < 6; i++) {
      s[i] = analogRead(i);
      maximum[i] = max(maximum[i], s[i]);
      minimum[i] = min(minimum[i], s[i]);
    }
  }
  motor(0, 0);
  for (int i = 0; i < 6; i++) {
    mid[i] = minimum[i] + (maximum[i] - minimum[i]) * 0.4;
    EEPROM.write(i, mid[i] / 4);
    delay(10);
    EEPROM.write(i + 6, maximum[i] / 4);
    delay(10);
    EEPROM.write(i + 12, minimum[i] / 4);
    delay(10);
  }
}

// ================== DEBUG HELPERS ==================
void analog_reading() {
  while (1) {
    for (int i = 5; i >= 0; i--) {
      s[i] = analogRead(i);
      Serial.print(String(s[i]) + " ");
    }
    Serial.println();
  }
}

void digital_reading() {
  while (1) {
    reading();
    for (int i = 5; i >= 0; i--)
      Serial.print(String(s[i]) + " ");
    Serial.println(sensor);
  }
}

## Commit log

2026-06-13 Create ESP32code
2026-08-06 Add QR code scanner with Arduino Mega integration
2026-08-06 Refactor Arduino connection and QR code handling
2026-08-19 docs: Add quick reference guide with circuit diagram, process flow, and deployment instructions
2026-08-19 Revise track layout diagram in README
    Updated suggested track layout in README.
2026-08-19 Fix circuit diagram reference in README
    Updated circuit diagram reference and corrected image path.
2026-08-19 Replace mermaid electrical architecture diagram with Proposal/circuit diagram.png image
2026-08-19 Add circuit diagram image to README
    Added an image of the circuit diagram to the README.
